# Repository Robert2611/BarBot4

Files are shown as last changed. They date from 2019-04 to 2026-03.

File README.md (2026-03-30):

# BarBot4

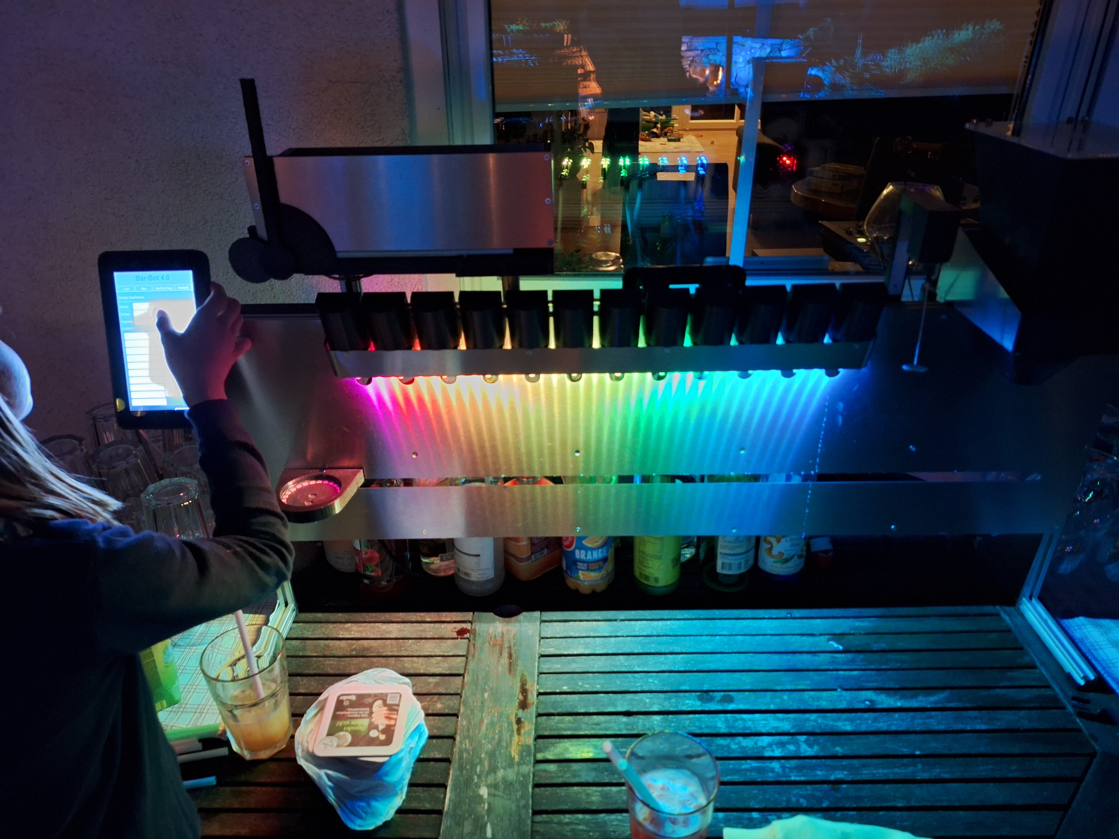
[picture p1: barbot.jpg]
BarBot4


BarBot4 is a high-end, automated cocktail-mixing machine designed for precision and ease of use. It combines a Raspberry Pi-powered touch interface with modular microcontroller-based hardware to deliver perfectly mixed drinks every time.

## ✨ Features

- **Automated Mixing**: Precise control over ingredient dispensing and sequence.
- **Modular Design**: Support for peripheral modules like mixers, crushers, and straw dispensers.
- **Smart Scale Integration**: Real-time weight tracking for accurate pours.
- **Touchscreen GUI**: Modern, user-friendly interface built with PyQt5.
- **Customizable Recipes**: Easily create and manage your own cocktail database.
- **Wireless Communication**: Bluetooth-based control between the Pi and hardware sub-modules.

## 🛠️ Hardware Requirements

To build a BarBot4, you will need:
- **Main Controller**: Raspberry Pi (Bookworm or Trixie recommended) with a touchscreen.
- **Mainboard**: ESP32-based controller for motor and pump management.
- **Balance Board (Mandatory)**: An Atmega328p-based module for accurate weight sensing.
    - **Sensor**: HX711 Load Cell amplifier for weight measurement.
- **Optional Sub-modules**: AVR (Arduino) based modules for specific functions (e.g., Ice Crusher, Mixer, Straw Dispenser).
- **Firmware**: Pre-compiled binaries for all modules are available in the [GitHub Releases](https://github.com/Robert2611/BarBot4/releases).

## 🚀 Quick Start

### 1. Firmware Installation
For ease of setup, pre-compiled firmware binaries are automatically generated and attached to each [GitHub Release](https://github.com/Robert2611/BarBot4/releases).

1. Download the `firmware.zip` from the latest release.
2. Extract the archive on a Windows PC.
3. Run `flash.bat` and follow the on-screen instructions to flash your Mainboard (ESP32) or sub-modules (Atmega328p).
   - *Note: Flashing scripts for Linux/macOS users can be found in the `/firmware` directory.*

### 2. Pi Software Installation
The easiest way to set up the BarBot software on a fresh Raspberry Pi OS is to use the automated install script:

```bash
curl -sSL https://raw.githubusercontent.com/Robert2611/BarBot4/master/raspberry/install.sh | bash
```

This script handles dependencies, virtual environment setup, and system configuration. **It also configures the application to start automatically on boot**, so there is no need to run it manually after the initial setup.

## 🛠️ Development

If you are developing for BarBot4 or need to run it manually for testing, you can use the following commands:

### Running BarBot Manually
- `barbot`: Start the standard interface.
- `barbot-demo`: Start in demo mode (uses mockup hardware for testing).
- `barbot-with-log`: Start with console logging enabled.

### Local Installation
To install the package in editable mode from the repository:
```bash
cd raspberry
pip install -e .
```

## 📂 Project Structure

The project is organized to separate physical design, electronics, and software:
- `/CAD`: 3D models for the chassis and components.
- `/elektronik`: PCB designs and schematics.
- `/firmware`: Microcontroller source code (C++/PlatformIO).
- `/raspberry`: Main Python application logic and GUI.

For a detailed breakdown of all directories, please refer to [README_STRUCTURE.md](./README_STRUCTURE.md).

## 🤝 Contributing

Contributions are welcome! Whether it's a new recipe, a bug fix, or a feature request, feel free to open an issue or submit a pull request.

## 📜 License
[MIT](https://choosealicense.com/licenses/mit/)

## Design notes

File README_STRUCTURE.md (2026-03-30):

# BarBot4 Project Structure

This file provides an overview of the folder organization for the BarBot4 project.

## Root Directory
- `/CAD`: 3D models and mechanical designs for the bar bot's physical structure.
- `/elektronik`: PCB designs, schematics, and other electronic documentation.
- `/firmware`: Source code for all microcontroller-based components.
    - `/mainboard`: Primary controller firmware (PlatformIO project).
    - `/balance`: Firmware for the integrated scale/balance.
    - `/shared`: Common code and headers shared across multiple firmware projects.
    - `/mixer`, `/crusher`, `/straw`, `/sugar`: Firmware for specialized peripheral modules.
- `/raspberry`: Main application and control software running on a Raspberry Pi.
    - `/recipe-collections`: Organized recipe sets (e.g., `standard`, `party-set`).
    - `/barbot`: The core Python source code.
        - `/gui`: PyQt5-based user interface components.
        - `/logic`: Core business logic, hardware interaction, and cocktail preparation flows.
        - `/test`: Unit tests and integration tests for the Python application.
    - `install.sh`: Automated setup script for initializing the Raspberry Pi environment.
- `/info`: General project documentation, build guides, and auxiliary information.

## Technology Stack
- **Firmware**: C++ (ESP32 for the Mainboard, AVR/Arduino for sub-modules) managed via PlatformIO.
- **Pi App**: Python 3 with PyQt5 for the GUI.
- **Hardware Communication**: Serial/Bluetooth-based protocols between the Raspberry Pi and sub-modules.

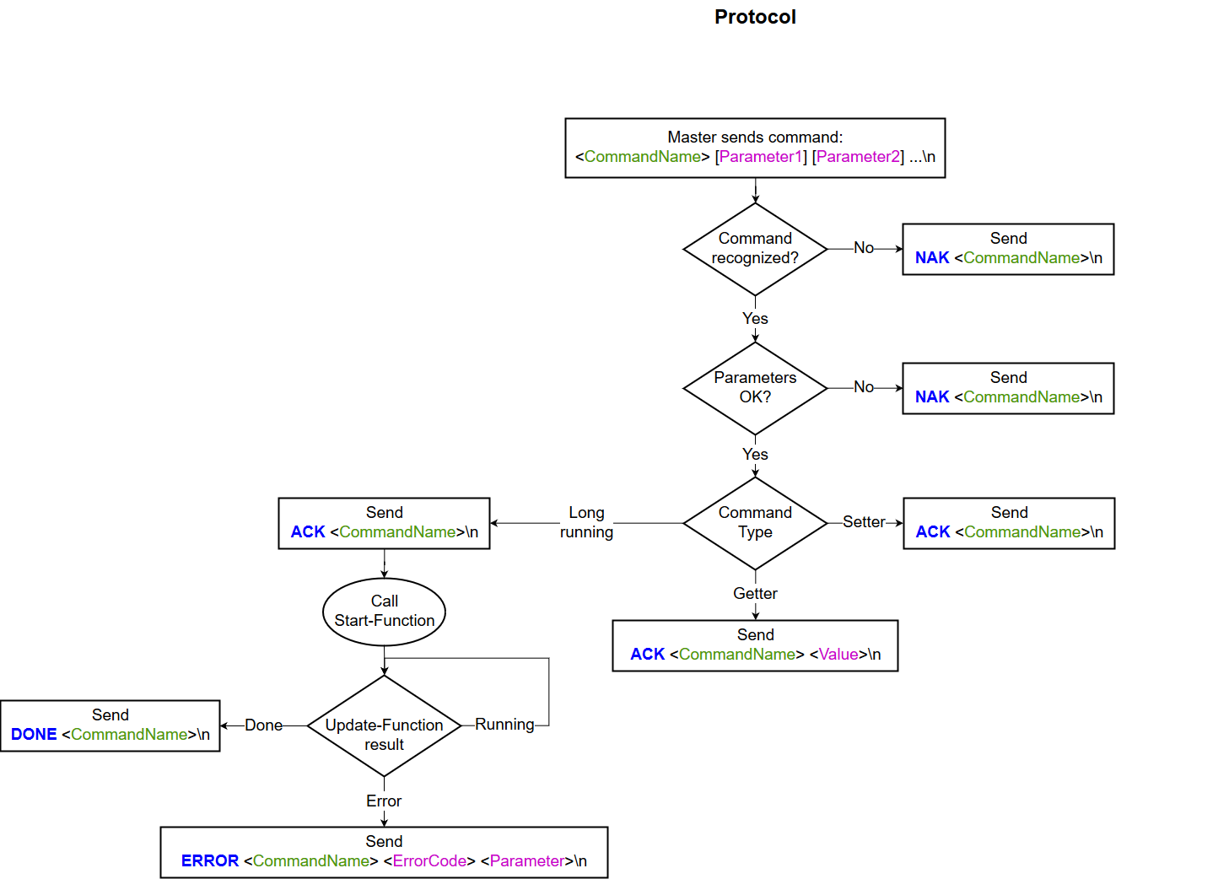
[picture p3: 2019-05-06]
info/Protocol Chart.png

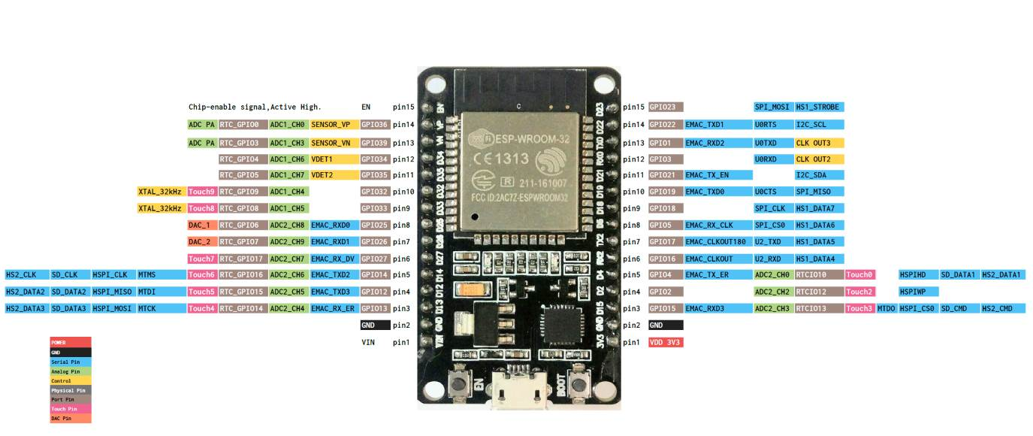
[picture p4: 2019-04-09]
info/ESP32 ports.bmp

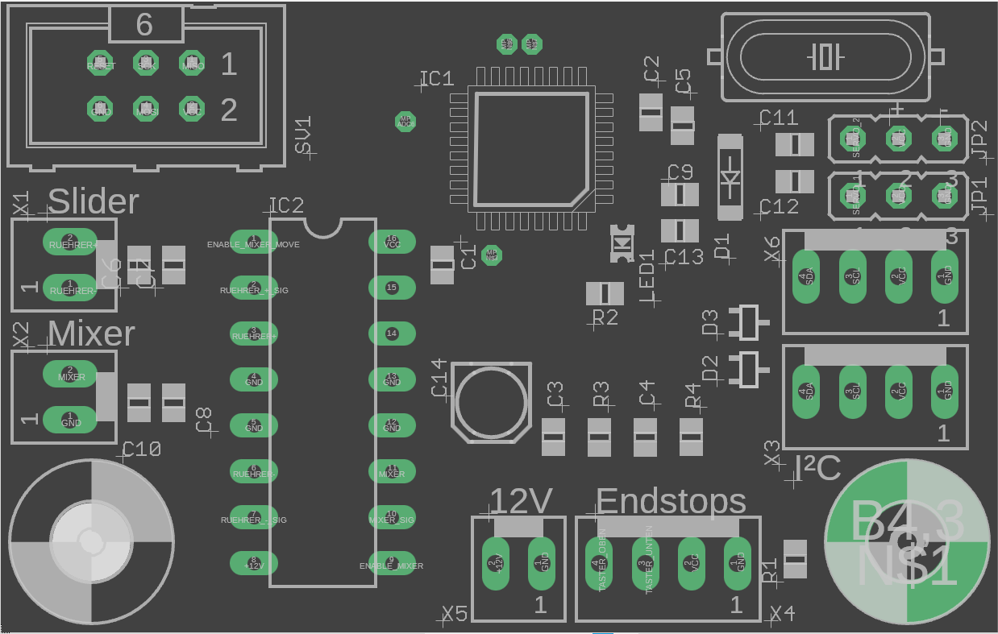
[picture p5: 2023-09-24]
elektronik/Mixer/Mixer Board.png

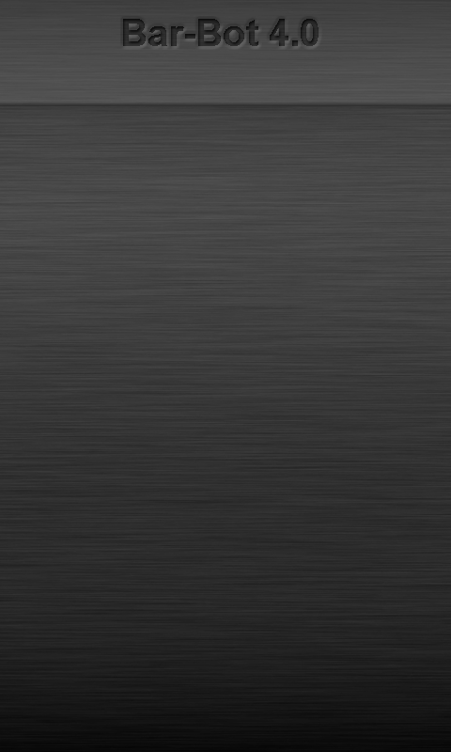
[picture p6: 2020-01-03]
raspberry/barbot/gui/asset/Background.png

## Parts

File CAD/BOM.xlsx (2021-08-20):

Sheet: Kaufteile
Artikelnummer | Beschreibung | Lieferant/Platform | Artikelnummer/-name | Link | Anzahl/Länge pro VE | Preis pro VE | Verpackungs Einheit (VE) | Preis pro Stück/Meter
KT-001 | Pumpe | Ali Express |  | https://www.aliexpress.com/item/32902208606.html | 1 | 4.00 € |  | 4.00 €
KT-002 | DC Motor für Rührer | ebay | Gleichstrommotor Johnson 20703 |  | 3 | 8.67 € |  | 2.89 €
KT-003 | Schlauch | Schlauch-profi.de | Silikonschlauch Lebensmittel 6 x 8 mm |  | 25 | 36.95 € |  | 1.48 €
KT-004 | Neopixel Stripe | Ali Express | WS2812B stripe, 60 LED/Meter | https://www.aliexpress.com/item/32956009458.html | 5 | 16.59 € | m | 3.32 €
KT-005 | Rührer | eBay | Milchaufschäumer | https://www.ebay.de/itm/202533912887 | 1 | 4.89 € |  | 4.89 €
KT-006 | Zahnriemen und Zahnräder | Ali Express | 2x Riemenscheibe (20Zähne) 2,5m Zahnriemen 2x Riemenscheibe mit Kugellager | https://www.aliexpress.com/item/4000091123800.html | 1 | 3.38 € |  | 3.38 €
KT-007 | Rad | Ali Express | V-Slot wheel POM | https://www.aliexpress.com/item/32777946833.html | 10 | 5.97 € |  | 0.60 €
KT-008 | V-Slot Profil | Jamoprint | V Slot Profile 20x40 | https://jamoprint.com/ | 3 | 57.75 € |  | 19.25 €
KT-009 | Schrittmotor | eBay | NEMA 17 | https://www.ebay.de/itm/5PCS-Schrittmotor-Nema-17-Stepper-Motor-42Ncm-1-5-A-4-Draht-Fur-3D-Drucker-DIY/293278143194 | 5 | 35.99 € |  | 7.20 €
KT-010 | Alu Profil |  |  |  | 1 | 3.20 € | m | 3.20 €
KT-011 | Filament | Prusa | PETG Galaxy Black | https://shop.prusa3d.com/de/prusament/1006-prusament-petg-prusa-galaxy-black-1kg.html | 1 | 29.99 € | kg | 29.99 €
KT-012 | LED Ring | Ali Express | 24 LEDs | https://www.aliexpress.com/item/33040868012.html | 1 | 2.52 € |  | 2.52 €
KT-013 | Rollenschalter | eBay | KW12-3 Micro | https://www.ebay.de/itm/192740457273 | 10 | 2.22 € |  | 0.22 €
KT-014 | Alu Winkel | eBay |  |  | 1.5 | 22.96 € | m | 15.31 €
KT-015 | Motor auf u. ab | eBay | 12V 100RPM | https://www.ebay.de/itm/DC-3V-6V-12V-100RPM-Micro-Speed-Reduction-Gear-Motor-Metal-Gearbox-Wheel-Shaft/273996287398 | 5 | 13.30 € |  | 2.66 €
KT-016 | Wiegebalken | Ali Express | 1 kg | https://www.aliexpress.com/item/32864971873.html | 1 | 1.89 € |  | 1.89 €
KT-017 | Igus-Schiene | Igus | NS-01-17, Länge: 160 mm | https://www.igus.de/product/722 | 3 | 17.34 € |  | 5.78 €
KT-018 | Igus-Schlitten | Igus | NW-02-17 | https://www.igus.de/product/920 | 11 | 25.03 € |  | 2.28 €
KT-019 | Servo klein | eBay | Microservo SG90 | https://www.ebay.de/itm/Micro-SG90-Servo-Motor-9G-fur-RC-Hubschrauber-Flugzeug-Arduino-Control-mini/174238436675 | 10 | 15.59 € |  | 1.56 €
KT-020 | Servo groß | eBay |  | https://www.ebay.de/itm/1-4-Digital-Metall-Gear-RC-MG996R-Lenk-Servo-55g-15Kg-Upgrade-RC-Universe/233464162034 | 4 | 16.29 € |  | 4.07 €
KT-021 | Energiekette | Ali Express | Innere Höhe 7mm | https://www.aliexpress.com/item/32214281467.html | 1 | 4.93 € |  | 4.93 €
KT-022 | Raspberry Pi | Raspishop | Raspberry Pi 4 | https://www.rasppishop.de/Raspberry-Pi-4-Modell-B-2GB-SDRAM | 1 | 39.19 € |  | 39.19 €
KT-023 | Touchscreen | Raspishop | Raspberry Pi 7" Touchscreen Display | https://www.rasppishop.de/Raspberry-Pi-7-Touchscreen-Display | 1 | 71.99 € |  | 71.99 €
KT-024 | Netzteil | Raspishop | 5,1V 2,5A Micro-USB Steckernetzteil | https://www.rasppishop.de/51V-25A-Micro-USB-Steckernetzteil | 1 | 7.99 € |  | 7.99 €
KT-025 | Abdeckblech | laserteile4you |  |  | 6 | 100.98 € |  | 16.83 €
KT-026 | Abdeckblech Pumpen | laserteile4you |  |  | 6 | 41.28 € |  | 6.88 €
KT-027 | PMMA | eBay | 3mm x (250mm x 200mm) | https://www.ebay.de/itm/Plexi-Platte-2-15-mm-PMMA-Acrylglas-Acrylplatte-Zuchnit-Schild-250-500-mm/324015302606 | 8 | 5.82 € | Scheiben | 0.73 €
KT-028 | SD-Karte | Raspishop | 16 GB | https://www.rasppishop.de/Sandisk-microSDHC-UHS-I-A1-16GB-Class10 | 1 | 7.30 € |  | 7.30 €
KT-029 | Motor Crusher |  |  |  | 1 | 25.00 € |  | 25.00 €
KT-030 | Eiscrusher | gastro-spirit.de |  | https://www.gastro-spirit.de/eiszerkleinerer-mit-handkurbel-ohne-saugfuss-1399001.html | 6 | 50.64 € |  | 8.44 €
KT-050 | DIN 912 M3x30 | Frantos |  |  | 100 | 7.00 € |  | 0.07 €
KT-051 | Mutter M3 | Frantos |  |  | 1000 | 9.28 € |  | 0.01 €
KT-052 | DIN 912 M4x14 | Frantos |  |  | 500 | 20.83 € |  | 0.04 €
KT-053 | Unterlegscheibe A4,3 | Frantos | DIN 125 A M4 |  | 1000 | 5.47 € |  | 0.01 €
KT-054 | Nutenstein M4 | Ali Express | 20-M4 | https://www.aliexpress.com/item/33053406103.html | 20 | 3.00 € |  | 0.15 €
KT-055 | Hammerkopf Mutter M4 | Ali Express |  | https://www.aliexpress.com/item/32333227356.html | 100 | 7.00 € |  | 0.07 €
KT-056 | DIN 912 M3x6 | Frantos |  |  | 100 | 4.00 € |  | 0.04 €
KT-057 | DIN 912 M5x25 | Frantos |  |  | 500 | 34.87 € |  | 0.07 €
KT-058 | Mutter M5 | Frantos |  |  | 1000 | 15.35 € |  | 0.02 €
KT-059 | Unterlegscheibe A5,3 | Frantos | DIN 125 A M5 |  | 1000 | 7.02 € |  | 0.01 €
KT-060 | Karosseriescheibe M5 | Frantos | 5,3x15 |  | 500 | 10.41 € |  | 0.02 €
KT-061 | DIN 7991 M5x30 | Frantos |  |  | 200 | 11.71 € |  | 0.06 €
KT-062 | DIN 912 M3x10 | Frantos |  |  | 100 | 2.15 € |  | 0.02 €
KT-063 | Unterlegscheibe A3,2 | Frantos | DIN 125 A M3 |  | 1000 | 4.52 € |  | 0.00452 €
KT-064 | DIN 7991 M3x8 | Frantos |  |  | 100 | 3.07 € |  | 0.03 €
KT-065 | DIN 7991 M4x18 | Frantos |  |  | 500 | 14.40 € |  | 0.03 €
KT-066 | DIN 7991 M4x12 | Frantos |  |  | 500 | 10.89 € |  | 0.02 €
KT-067 | Nutenstein M3 | Ali Express | 20-M3 | https://www.aliexpress.com/item/33053406103.html | 20 | 3.00 € |  | 0.15 €
KT-068 | Flanschkopfschraube M5x16 | Frantos | ISO 7380-2 |  | 500 | 25.05 € |  | 0.05 €
KT-069 | DIN 912 M4x10 | Frantos |  |  | 500 | 17.55 € |  | 0.04 €
KT-070 | DIN 7991 M3x10 | Frantos |  |  | 100 | 3.14 € |  | 0.03 €
KT-071 | DIN 912 M5x10 | Frantos |  |  | 500 | 22.49 € |  | 0.04 €
KT-072 | Nutenstein M5 | Ali Express | 20-M5 | https://www.aliexpress.com/item/33053406103.html | 20 | 3.00 € |  | 0.15 €
KT-073 | DIN 912 M2x20 | Frantos |  |  | 500 | 24.81 € |  | 0.05 €
KT-074 | Mutter M2 | Frantos |  |  | 500 | 5.36 € |  | 0.01 €
KT-075 | DIN 7991 M3x12 | Frantos |  |  | 100 | 3.01 € |  | 0.03 €
KT-076 | DIN 912 M3x20 | Frantos |  |  | 100 | 2.88 € |  | 0.03 €
KT-077 | Hammerkopf Mutter M3 | Ali Express |  | https://www.aliexpress.com/item/32333227356.html | 100 | 7.00 € |  | 0.07 €
KT-078 | Gewindestift M3x5 | Frantos |  |  | 500 | 7.08 € |  | 0.01 €
KT-079 | O-Ring 45x2,5 | Fortuna
KT-080 | Abdeckblech Strohhalmmagazin vorne | laserteile4you |  |  | 1 | 6.85 € |  | 6.85 €
KT-081 | Abdeckblech Strohhalmmagazin hinten | laserteile4you |  |  | 1 | 6.74 € |  | 6.74 €
KT-082 | DIN 933 M6x20
KT-083 | Knotenblech |  |  |  | 2 |  |  | 0.00 €
KT-084 | DIN 7991 M3x16 | Frantos |  |  | 100 | 3.00 € |  | 0.03 €
KT-085 | Vierkantmutter M3 |  |  |  | 1 | 0.00 € |  | 0.00 €
KT-086 | Vierkant 8x8
KT-087 | Stecknuss SW13
KT-088 | Crusher Blech1
KT-089 | Crusher Blech2
KT-090 | Batterie Crusher
KT-999 | Dummy |  |  |  | 1 | 0.00 € |  | 0.00 €

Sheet: Fertigungsteile
Artikelnummer | Beschreibung | Artikelnummer Kaufteil | Beschreibung Kaufteil | Menge Kaufteil | Preis
FT-001 | Profil 20x20 400 mm | KT-010 | Alu Profil | 0.4 | 1.28 €
FT-002 | Profil 20x20 300 mm | KT-010 | Alu Profil | 0.3 | 0.96 €
FT-003 | Profil 20x20 1040 mm | KT-010 | Alu Profil | 1.04 | 3.33 €
FT-004 | Profil 20x20 1000 mm | KT-010 | Alu Profil | 1 | 3.20 €
FT-005 | V-Slot Profil 1000 mm | KT-008 | V-Slot Profil | 1 | 19.25 €
FT-006 | Schlitten | KT-014 | Alu Winkel | 0.1 | 1.53 €
FT-007 | PMMA Scheibe | KT-027 | PMMA | 1 | 0.73 €
FT-008 | Igus Schiene mit Fase | KT-017 | Igus-Schiene | 1 | 5.78 €
FT-009 | Rührer Unterstüztungswinkel | KT-014 | Alu Winkel | 0.016 | 0.24 €
FT-010 | Profil 20x20 90mm | KT-010 | Alu Profil | 0.09 | 0.29 €
FT-011 | Wiegebalken | KT-016 | Wiegebalken |  | 0.00 €
FT-012 | Profil 20x20 100 mm | KT-010 | Alu Profil |  | 0.00 €
FT-013 | Welle | KT-086 | Vierkant 8x8 |  | #VALUE!
DT-001 | Schrittmotorhalter | KT-011 | Filament | 0.016 | 0.48 €
DT-002 | Riemenumlenkung | KT-011 | Filament | 0.021 | 0.63 €
DT-003 | Box Hauptplatine | KT-011 | Filament | 0.064 | 1.92 €
DT-004 | Deckel Hauptplatine | KT-011 | Filament | 0.019 | 0.57 €
DT-005 | Klemme Pumpenhalterung | KT-011 | Filament | 0.02 | 0.60 €
DT-006 | Pumpenhalterung | KT-011 | Filament | 0.013 | 0.39 €
DT-007 | Teller Teil 1 | KT-011 | Filament | 0.015 | 0.45 €
DT-008 | Teller Teil 2 | KT-011 | Filament | 0.027 | 0.81 €
DT-009 | Teller Teil 3 | KT-011 | Filament | 0.004 | 0.12 €
DT-010 | Riemenbefestigung rechts | KT-011 | Filament | 0.008 | 0.24 €
DT-011 | Riemenbefestigung links | KT-011 | Filament | 0.008 | 0.24 €
DT-012 | Abdeckplatte Rührermotor | KT-011 | Filament | 0.006 | 0.18 €
DT-013 | Box Wiegeplatine | KT-011 | Filament | 0.032 | 0.96 €
DT-014 | Deckel Wiegeplatine | KT-011 | Filament | 0.007 | 0.21 €
DT-015 | Schlauchführung | KT-011 | Filament | 0.005 | 0.15 €
DT-016 | Box Rührerplatine | KT-011 | Filament | 0.034 | 1.02 €
DT-017 | Deckel Rührerplatine | KT-011 | Filament | 0.007 | 0.21 €
DT-018 | Grundplatte Rührer | KT-011 | Filament | 0.042 | 1.26 €
DT-019 | Motorklemme | KT-011 | Filament | 0.003 | 0.09 €
DT-020 | Zahnrad | KT-011 | Filament | 0.003 | 0.09 €
DT-022 | Zahnstange Rührer | KT-011 | Filament | 0.039 | 1.17 €
DT-023 | Halterung Rührermotor | KT-011 | Filament | 0.038 | 1.14 €
DT-024 | Strohhalmmagazin | KT-011 | Filament | 0.163 | 4.89 €
DT-025 | Reibrad | KT-011 | Filament | 0.006 | 0.18 €
DT-026 | Motorhalterung Reibrad | KT-011 | Filament |  | 0.00 €
DT-027 | Verbindung Servo zu Schraube | KT-011 | Filament |  | 0.00 €
DT-028 | Drehbarer Arm | KT-011 | Filament |  | 0.00 €
DT-029 | Displayhalter | KT-011 | Filament |  | 0.00 €
DT-030 | Display Standfuß | KT-011 | Filament |  | 0.00 €
DT-031 | Kettenverbindung | KT-011 | Filament |  | 0.00 €
DT-032 | Verbinder Griff | KT-011 | Filament |  | 0.00 €
DT-033 | Griff | KT-011 | Filament |  | 0.00 €
DT-034 | Profilclip | KT-011 | Filament |  | 0.00 €
DT-035 | Adapter Displayhalterung | KT-011 | Filament |  | 0.00 €
DT-036 | Trichter Crusher | KT-011 | Filament |  | 0.00 €
DT-037 | Motorplatte Scheibenwischermotor | KT-011 | Filament |  | 0.00 €
DT-038 | Blende Crusher | KT-011 | Filament |  | 0.00 €
DT-039 | Eiswürfelbehälter | KT-011 | Filament |  | 0.00 €
DT-040 | Lagerung Crusherwelle | KT-011 | Filament |  | 0.00 €
DT-041 | Buchse/Fixierung | KT-011 | Filament |  | 0.00 €
DT-042 | Buchse | KT-011 | Filament |  | 0.00 €
DT-043 | Crusher Deckel | KT-011 | Filament |  | 0.00 €
DT-044 | Scharnier Teil1 | KT-011 | Filament |  | 0.00 €
DT-045 | Scharnier Teil2 | KT-011 | Filament |  | 0.00 €

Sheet: BOM
Rubrik | Artikelnummer | Anzahl | Beschreibung | Gesamtpreis | Ist Fertigungsteil | Artikelnummer Kaufteil | Menge Kaufteil | Beschreibung Kaufteil | Info
Rahmen | FT-001 | 2 | Profil 20x20 400 mm | 2.56 € | TRUE | KT-010 | 0.8 | Alu Profil
Rahmen | FT-002 | 2 | Profil 20x20 300 mm | 1.92 € | TRUE | KT-010 | 0.6 | Alu Profil
Rahmen | FT-003 | 1 | Profil 20x20 1040 mm | 3.33 € | TRUE | KT-010 | 1.04 | Alu Profil
Rahmen | FT-004 | 1 | Profil 20x20 1000 mm | 3.20 € | TRUE | KT-010 | 1 | Alu Profil
Rahmen | FT-005 | 1 | V-Slot Profil 1000 mm | 19.25 € | TRUE | KT-008 | 1 | V-Slot Profil
Rahmen | KT-004 | 1 | Neopixel Stripe | 3.32 € | FALSE | KT-004 | 1 | Neopixel Stripe
Rahmen | KT-025 | 1 | Abdeckblech | 16.83 € | FALSE | KT-025 | 1 | Abdeckblech
Rahmen | KT-009 | 1 | Schrittmotor | 7.20 € | FALSE | KT-009 | 1 | Schrittmotor
Rahmen | KT-013 | 1 | Rollenschalter | 0.22 € | FALSE | KT-013 | 1 | Rollenschalter
Rahmen | DT-001 | 1 | Schrittmotorhalter | 0.48 € | TRUE | KT-011 | 0.016 | Filament
Rahmen | DT-002 | 1 | Riemenumlenkung | 0.63 € | TRUE | KT-011 | 0.021 | Filament
Rahmen | DT-003 | 1 | Box Hauptplatine | 1.92 € | TRUE | KT-011 | 0.064 | Filament
Rahmen | DT-004 | 1 | Deckel Hauptplatine | 0.57 € | TRUE | KT-011 | 0.019 | Filament
Rahmen | KT-068 | 6 | Flanschkopfschraube M5x16 | 0.30 € | FALSE | KT-068 | 6 | Flanschkopfschraube M5x16
Rahmen | KT-069 | 3 | DIN 912 M4x10 | 0.11 € | FALSE | KT-069 | 3 | DIN 912 M4x10 | Box Hauptplatine
Rahmen | KT-053 | 3 | Unterlegscheibe A4,3 | 0.02 € | FALSE | KT-053 | 3 | Unterlegscheibe A4,3 | Box Hauptplatine
Rahmen | KT-054 | 3 | Nutenstein M4 | 0.45 € | FALSE | KT-054 | 3 | Nutenstein M4 | Box Hauptplatine
Rahmen | KT-056 | 4 | DIN 912 M3x6 | 0.16 € | FALSE | KT-056 | 4 | DIN 912 M3x6 | Box Hauptplatine
Rahmen | KT-071 | 8 | DIN 912 M5x10 | 0.36 € | FALSE | KT-071 | 8 | DIN 912 M5x10 | Motorhalter + Umlenker
Rahmen | KT-059 | 9 | Unterlegscheibe A5,3 | 0.06 € | FALSE | KT-059 | 9 | Unterlegscheibe A5,3 | Motorhalter + Umlenker
Rahmen | KT-057 | 1 | DIN 912 M5x25 | 0.07 € | FALSE | KT-057 | 1 | DIN 912 M5x25 | Motorhalter + Umlenker
Rahmen | KT-072 | 8 | Nutenstein M5 | 1.20 € | FALSE | KT-072 | 8 | Nutenstein M5 | Motorhalter + Umlenker
Rahmen | KT-064 | 4 | DIN 7991 M3x8 | 0.12 € | FALSE | KT-064 | 4 | DIN 7991 M3x8 | Motorhalter + Umlenker
Rahmen | KT-073 | 2 | DIN 912 M2x20 | 0.10 € | FALSE | KT-073 | 2 | DIN 912 M2x20 | Motorhalter + Umlenker
Rahmen | KT-074 | 2 | Mutter M2 | 0.02 € | FALSE | KT-074 | 2 | Mutter M2 | Motorhalter + Umlenker
Schlitten | FT-006 | 1 | Schlitten | 1.53 € | TRUE | KT-014 | 0.1 | Alu Winkel
Schlitten | KT-007 | 3 | Rad | 1.79 € | FALSE | KT-007 | 3 | Rad
Schlitten | KT-021 | 1 | Energiekette | 4.93 € | FALSE | KT-021 | 1 | Energiekette
Schlitten | KT-006 | 1 | Zahnriemen und Zahnräder | 3.38 € | FALSE | KT-006 | 1 | Zahnriemen und Zahnräder
Schlitten | KT-012 | 1 | LED Ring | 2.52 € | FALSE | KT-012 | 1 | LED Ring
Schlitten | KT-016 | 1 | Wiegebalken | 1.89 € | FALSE | KT-016 | 1 | Wiegebalken
Schlitten | FT-007 | 1 | PMMA Scheibe | 0.73 € | TRUE | KT-027 | 1 | PMMA
Schlitten | DT-007 | 1 | Teller Teil 1 | 0.45 € | TRUE | KT-011 | 0.015 | Filament
Schlitten | DT-008 | 1 | Teller Teil 2 | 0.81 € | TRUE | KT-011 | 0.027 | Filament
Schlitten | DT-009 | 1 | Teller Teil 3 | 0.12 € | TRUE | KT-011 | 0.004 | Filament
Schlitten | DT-010 | 1 | Riemenbefestigung rechts | 0.24 € | TRUE | KT-011 | 0.008 | Filament
Schlitten | DT-011 | 1 | Riemenbefestigung links | 0.24 € | TRUE | KT-011 | 0.008 | Filament
Schlitten | DT-012 | 1 | Abdeckplatte Rührermotor | 0.18 € | TRUE | KT-011 | 0.006 | Filament
Schlitten | DT-013 | 1 | Box Wiegeplatine | 0.96 € | TRUE | KT-011 | 0.032 | Filament
Schlitten | DT-014 | 1 | Deckel Wiegeplatine | 0.21 € | TRUE | KT-011 | 0.007 | Filament
Schlitten | KT-057 | 2 | DIN 912 M5x25 | 0.14 € | FALSE | KT-057 | 2 | DIN 912 M5x25
Schlitten | KT-058 | 6 | Mutter M5 | 0.09 € | FALSE | KT-058 | 6 | Mutter M5
Schlitten | KT-059 | 5 | Unterlegscheibe A5,3 | 0.04 € | FALSE | KT-059 | 5 | Unterlegscheibe A5,3
Schlitten | KT-060 | 1 | Karosseriescheibe M5 | 0.02 € | FALSE | KT-060 | 1 | Karosseriescheibe M5
Schlitten | KT-061 | 1 | DIN 7991 M5x30 | 0.06 € | FALSE | KT-061 | 1 | DIN 7991 M5x30
Schlitten | KT-062 | 5 | DIN 912 M3x10 | 0.11 € | FALSE | KT-062 | 5 | DIN 912 M3x10
Schlitten | KT-063 | 4 | Unterlegscheibe A3,2 | 0.02 € | FALSE | KT-063 | 4 | Unterlegscheibe A3,2
Schlitten | KT-051 | 5 | Mutter M3 | 0.05 € | FALSE | KT-051 | 5 | Mutter M3
Schlitten | KT-070 | 2 | DIN 7991 M3x10 | 0.06 € | FALSE | KT-070 | 2 | DIN 7991 M3x10
Schlitten | KT-064 | 4 | DIN 7991 M3x8 | 0.12 € | FALSE | KT-064 | 4 | DIN 7991 M3x8
Schlitten | KT-056 | 2 | DIN 912 M3x6 | 0.08 € | FALSE | KT-056 | 2 | DIN 912 M3x6
Schlitten | KT-065 | 3 | DIN 7991 M4x18 | 0.09 € | FALSE | KT-065 | 3 | DIN 7991 M4x18
Schlitten | KT-066 | 1 | DIN 7991 M4x12 | 0.02 € | FALSE | KT-066 | 1 | DIN 7991 M4x12
Schlitten | KT-067 | 2 | Nutenstein M3 | 0.30 € | FALSE | KT-067 | 2 | Nutenstein M3
Display | DT-029 | 1 | Displayhalter | 0.00 € | TRUE | KT-011 | 0 | Filament
Display | DT-030 | 1 | Display Standfuß | 0.00 € | TRUE | KT-011 | 0 | Filament
Display | KT-022 | 1 | Raspberry Pi | 39.19 € | FALSE | KT-022 | 1 | Raspberry Pi
Display | KT-023 | 1 | Touchscreen | 71.99 € | FALSE | KT-023 | 1 | Touchscreen
Display | KT-024 | 1 | Netzteil | 7.99 € | FALSE | KT-024 | 1 | Netzteil
Display | KT-028 | 1 | SD-Karte | 7.30 € | FALSE | KT-028 | 1 | SD-Karte
Pumpe | KT-001 | 12 | Pumpe | 48.00 € | FALSE | KT-001 | 12 | Pumpe
Pumpe | KT-003 | 3.6 | Schlauch | 5.32 € | FALSE | KT-003 | 3.6 | Schlauch
Pumpe | DT-005 | 12 | Klemme Pumpenhalterung | 7.20 € | TRUE | KT-011 | 0.24 | Filament
Pumpe | DT-006 | 12 | Pumpenhalterung | 4.68 € | TRUE | KT-011 | 0.156 | Filament
Pumpe | KT-050 | 24 | DIN 912 M3x30 | 1.68 € | FALSE | KT-050 | 24 | DIN 912 M3x30
Pumpe | KT-051 | 36 | Mutter M3 | 0.33 € | FALSE | KT-051 | 36 | Mutter M3
Pumpe | KT-052 | 24 | DIN 912 M4x14 | 1.00 € | FALSE | KT-052 | 24 | DIN 912 M4x14
Pumpe | KT-053 | 24 | Unterlegscheibe A4,3 | 0.13 € | FALSE | KT-053 | 24 | Unterlegscheibe A4,3
Pumpe | KT-055 | 24 | Hammerkopf Mutter M4 | 1.68 € | FALSE | KT-055 | 24 | Hammerkopf Mutter M4
Pumpe | KT-056 | 12 | DIN 912 M3x6 | 0.48 € | FALSE | KT-056 | 12 | DIN 912 M3x6
Rührer | KT-002 | 1 | DC Motor für Rührer | 2.89 € | FALSE | KT-002 | 1 | DC Motor für Rührer
Rührer | KT-005 | 1 | Rührer | 4.89 € | FALSE | KT-005 | 1 | Rührer
Rührer | KT-017 | 1 | Igus-Schiene | 5.78 € | FALSE | KT-017 | 1 | Igus-Schiene
Rührer | KT-018 | 2 | Igus-Schlitten | 4.55 € | FALSE | KT-018 | 2 | Igus-Schlitten
Rührer | KT-015 | 1 | Motor auf u. ab | 2.66 € | FALSE | KT-015 | 1 | Motor auf u. ab
Rührer | FT-009 | 1 | Rührer Unterstüztungswinkel | 0.24 € | TRUE | KT-014 | 0.016 | Alu Winkel
Rührer | FT-010 | 1 | Profil 20x20 90mm | 0.29 € | TRUE | KT-010 | 0.09 | Alu Profil
Rührer | KT-013 | 2 | Rollenschalter | 0.44 € | FALSE | KT-013 | 2 | Rollenschalter
Rührer | DT-012 | 1 | Abdeckplatte Rührermotor | 0.18 € | TRUE | KT-011 | 0.006 | Filament
Rührer | DT-016 | 1 | Box Rührerplatine | 1.02 € | TRUE | KT-011 | 0.034 | Filament
Rührer | DT-017 | 1 | Deckel Rührerplatine | 0.21 € | TRUE | KT-011 | 0.007 | Filament
Rührer | DT-018 | 1 | Grundplatte Rührer | 1.26 € | TRUE | KT-011 | 0.042 | Filament
Rührer | DT-019 | 1 | Motorklemme | 0.09 € | TRUE | KT-011 | 0.003 | Filament
Rührer | DT-020 | 1 | Zahnrad | 0.09 € | TRUE | KT-011 | 0.003 | Filament
Rührer | DT-022 | 1 | Zahnstange Rührer | 1.17 € | TRUE | KT-011 | 0.039 | Filament
Rührer | DT-023 | 1 | Halterung Rührermotor | 1.14 € | TRUE | KT-011 | 0.038 | Filament
Rührer | KT-075 | 4 | DIN 7991 M3x12 | 0.12 € | FALSE | KT-075 | 4 | DIN 7991 M3x12 | Zahnstange an Schlitten
Rührer | KT-069 | 2 | DIN 912 M4x10 | 0.07 € | FALSE | KT-069 | 2 | DIN 912 M4x10 | Grundplatte an Profil
Rührer | KT-053 | 2 | Unterlegscheibe A4,3 | 0.01 € | FALSE | KT-053 | 2 | Unterlegscheibe A4,3 | Grundplatte an Profil
Rührer | KT-055 | 2 | Hammerkopf Mutter M4 | 0.14 € | FALSE | KT-055 | 2 | Hammerkopf Mutter M4 | Grundplatte an Profil
Rührer | KT-068 | 1 | Flanschkopfschraube M5x16 | 0.05 € | FALSE | KT-068 | 1 | Flanschkopfschraube M5x16 | Profil an Profil
Rührer | KT-077 | 2 | Hammerkopf Mutter M3 | 0.14 € | FALSE | KT-077 | 2 | Hammerkopf Mutter M3 | Schiene an Profil
Rührer | KT-075 | 2 | DIN 7991 M3x12 | 0.06 € | FALSE | KT-075 | 2 | DIN 7991 M3x12 | Schiene an Profil
Rührer | KT-062 | 2 | DIN 912 M3x10 | 0.04 € | FALSE | KT-062 | 2 | DIN 912 M3x10 | DT an Winkel
Rührer | KT-084 | 2 | DIN 7991 M3x16 | 0.06 € | FALSE | KT-084 | 2 | DIN 7991 M3x16 | DT an Winkel
Rührer | KT-075 | 1 | DIN 7991 M3x12 | 0.03 € | FALSE | KT-075 | 1 | DIN 7991 M3x12 | Abdeckung
Rührer | KT-073 | 4 | DIN 912 M2x20 | 0.20 € | FALSE | KT-073 | 4 | DIN 912 M2x20 | Endschalter
Rührer | KT-074 | 4 | Mutter M2 | 0.04 € | FALSE | KT-074 | 4 | Mutter M2 | Endschalter
Rührer | KT-076 | 2 | DIN 912 M3x20 | 0.06 € | FALSE | KT-076 | 2 | DIN 912 M3x20 | Motorklemme
Rührer | KT-051 | 2 | Mutter M3 | 0.02 € | FALSE | KT-051 | 2 | Mutter M3 | Motorklemme
Rührer | KT-062 | 2 | DIN 912 M3x10 | 0.04 € | FALSE | KT-062 | 2 | DIN 912 M3x10 | Platinenbox
Rührer | KT-063 | 4 | Unterlegscheibe A3,2 | 0.02 € | FALSE | KT-063 | 4 | Unterlegscheibe A3,2 | Platinenbox
Rührer | KT-056 | 2 | DIN 912 M3x6 | 0.08 € | FALSE | KT-056 | 2 | DIN 912 M3x6 | Platinenbox
Rührer | KT-085 | 1 | Vierkantmutter M3 | 0.00 € | FALSE | KT-085 | 1 | Vierkantmutter M3 | Zahnrad
Rührer | KT-078 | 1 | Gewindestift M3x5 | 0.01 € | FALSE | KT-078 | 1 | Gewindestift M3x5 | Zahnrad
Strohhalm | KT-019 | 1 | Servo klein | 1.56 € | FALSE | KT-019 | 1 | Servo klein
Strohhalm | KT-020 | 1 | Servo groß | 4.07 € | FALSE | KT-020 | 1 | Servo groß
Strohhalm | DT-024 | 1 | Strohhalmmagazin | 4.89 € | TRUE | KT-011 | 0.163 | Filament
Strohhalm | DT-025 | 1 | Reibrad | 0.18 € | TRUE | KT-011 | 0.006 | Filament
Strohhalm | DT-026 | 1 | Motorhalterung Reibrad | 0.00 € | TRUE | KT-011 | 0 | Filament
Strohhalm | DT-027 | 1 | Verbindung Servo zu Schraube | 0.00 € | TRUE | KT-011 | 0 | Filament
Strohhalm | DT-028 | 1 | Drehbarer Arm | 0.00 € | TRUE | KT-011 | 0 | Filament
Crusher | KT-029 | 1 | Motor Crusher | 25.00 € | FALSE | KT-029 | 1 | Motor Crusher
Crusher | KT-030 | 1 | Eiscrusher | 8.44 € | FALSE | KT-030 | 1 | Eiscrusher

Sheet: Auswertung
Zeilenbeschriftungen | Summe von Gesamtpreis | Zeilenbeschriftungen | Summe von Gesamtpreis | Summe von Menge Kaufteil | Zeilenbeschriftungen | Gesamtmenge
(Leer) | 36.01 € | Abdeckblech | 20.5 | 1 | KT-001 | 12
Ali Express | 69.97 € | Alu Profil | 11.008 | 3.44 | KT-002 | 1
ebay | 25.75 € | Alu Winkel | 1.530666667 | 0.1 | KT-003 | 3.6
Frantos | 6.50 € | DC Motor für Rührer | 2.89 | 1 | KT-004 | 1
gastro-spirit.de | 8.44 € | DIN 7991 M3x10 | 0.0628 | 2 | KT-005 | 1
Igus | 10.33 € | DIN 7991 M3x12 | 0.0602 | 2 | KT-006 | 1
Jamoprint | 19.25 € | DIN 7991 M3x8 | 0.2456 | 8 | KT-007 | 3
laserteile4you | 20.50 € | DIN 7991 M4x12 | 0.02178 | 1 | KT-008 | 1
Prusa | 20.45 € | DIN 7991 M4x18 | 0.0864 | 3 | KT-009 | 1
Raspishop | 126.47 € | DIN 7991 M5x30 | 0.05855 | 1 | KT-010 | 3.44
Schlauch-profi.de | 5.32 € | DIN 912 M2x20 | 0.29772 | 6 | KT-011 | 0.682
Gesamtergebnis | 348.99 € | DIN 912 M3x10 | 0.1505 | 7 | KT-012 | 1
 |  | DIN 912 M3x20 | 0.0576 | 2 | KT-013 | 1
 |  | DIN 912 M3x30 | 1.68 | 24 | KT-014 | 0.1
 |  | DIN 912 M3x6 | 0.8 | 20 | KT-015 | 1
 |  | DIN 912 M4x10 | 0.1755 | 5 | KT-016 | 1
 |  | DIN 912 M4x14 | 0.99984 | 24 | KT-017 | 1
 |  | DIN 912 M5x10 | 0.35984 | 8 | KT-018 | 2
 |  | DIN 912 M5x25 | 0.20922 | 3 | KT-019 | 1
 |  | Dummy | 0 | 0 | KT-020 | 1
 |  | Eiscrusher | 8.44 | 1 | KT-021 | 1
 |  | Energiekette | 4.93 | 1 | KT-022 | 1
 |  | Filament | 20.45318 | 0.682 | KT-023 | 1
 |  | Flanschkopfschraube M5x16 | 0.3507 | 7 | KT-024 | 1
 |  | Gewindestift M3x5 | 0.01416 | 1 | KT-025 | 1
 |  | Hammerkopf Mutter M3 | 0.07 | 1 | KT-027 | 1
 |  | Hammerkopf Mutter M4 | 1.82 | 26 | KT-028 | 1
 |  | Igus-Schiene | 5.781233333 | 1 | KT-029 | 1
 |  | Igus-Schlitten | 4.551109091 | 2 | KT-030 | 1
 |  | Karosseriescheibe M5 | 0.02082 | 1 | KT-050 | 24
 |  | LED Ring | 2.52 | 1 | KT-051 | 43
 |  | Motor auf u. ab | 2.66 | 1 | KT-052 | 24
 |  | Motor Crusher | 25 | 1 | KT-053 | 29
 |  | Mutter M2 | 0.06432 | 6 | KT-054 | 3
 |  | Mutter M3 | 0.39904 | 43 | KT-055 | 26
 |  | Mutter M5 | 0.0921 | 6 | KT-056 | 20
 |  | Neopixel Stripe | 3.318 | 1 | KT-057 | 3
 |  | Netzteil | 7.99 | 1 | KT-058 | 6
 |  | Nutenstein M3 | 0.6 | 4 | KT-059 | 14
 |  | Nutenstein M4 | 0.45 | 3 | KT-060 | 1
 |  | Nutenstein M5 | 1.2 | 8 | KT-061 | 1
 |  | PMMA | 0.7275 | 1 | KT-062 | 7
 |  | Pumpe | 48 | 12 | KT-063 | 8
 |  | Rad | 1.791 | 3 | KT-064 | 8
 |  | Raspberry Pi | 39.19 | 1 | KT-065 | 3
 |  | Rollenschalter | 0.222 | 1 | KT-066 | 1
 |  | Rührer | 4.89 | 1 | KT-067 | 4
 |  | Schlauch | 5.3208 | 3.6 | KT-068 | 7
 |  | Schrittmotor | 7.198 | 1 | KT-069 | 5
 |  | SD-Karte | 7.3 | 1 | KT-070 | 2
 |  | Servo groß | 4.0725 | 1 | KT-071 | 8
 |  | Servo klein | 1.559 | 1 | KT-072 | 8
 |  | Touchscreen | 71.99 | 1 | KT-073 | 6
 |  | Unterlegscheibe A3,2 | 0.03616 | 8 | KT-074 | 6
 |  | Unterlegscheibe A4,3 | 0.15863 | 29 | KT-075 | 2
 |  | Unterlegscheibe A5,3 | 0.09828 | 14 | KT-076 | 2
 |  | V-Slot Profil | 19.25 | 1 | KT-077 | 1
 |  | Wiegebalken | 1.89 | 1 | KT-078 | 1
 |  | Zahnriemen und Zahnräder | 3.38 | 1 | KT-999 | 0
 |  | Gesamtergebnis | 348.9927491 | 319.822 | Gesamtergebnis | 319.822

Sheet: Bestellungen
Artikelnummer Kaufteil | Beschreibung Kaufteil | Benötigt pro BarBot | Benötigt gesamt | Vorhanden | Bestellt | Noch bestellen | Wer Bestellt?
KT-001 | Pumpe | 12 | 72 | 24 | 13 | 35 | Jeder einzeln
KT-002 | DC Motor für Rührer | 1 | 6 | 1 |  | 5 | -
KT-003 | Schlauch | 3.6 | 21.6 | 30 |  | 0
KT-004 | Neopixel Stripe | 1 | 6 | 5 |  | 1 | Marinus
KT-005 | Rührer | 1 | 6 | 6 |  | 0
KT-006 | Zahnriemen und Zahnräder | 1 | 6 | 2 | 4 | 0
KT-007 | Rad | 3 | 18 | 5 | 10 | 0 | Nils
KT-008 | V-Slot Profil | 1 | 6 | 4 |  | 0 | Nils
KT-009 | Schrittmotor | 1 | 6 | 6 |  | 0
KT-010 | Alu Profil | 3.44 | 20.64 | 25 |  | 0
KT-011 | Filament | 0.682 | 4.092 | 2 |  | 2.092
KT-012 | LED Ring | 1 | 6 | 1 | 5 | 0
KT-013 | Rollenschalter | 1 | 6 | 10 |  | 0
KT-014 | Alu Winkel | 0.1 | 0.6 | 1 |  | 0
KT-015 | Motor auf u. ab | 1 | 6 | 1 | 5 | 0
KT-016 | Wiegebalken | 1 | 6 | 1 | 5 | 0
KT-017 | Igus-Schiene | 1 | 6 | 6 |  | 0
KT-018 | Igus-Schlitten | 2 | 12 | 14 |  | 0
KT-019 | Servo klein | 1 | 6 | 10 |  | 0
KT-020 | Servo groß | 1 | 6 | 2 | 4 | 0
KT-021 | Energiekette | 1 | 6 | 2 | 4 | 0
KT-022 | Raspberry Pi | 1 | 6 | 1 |  | 5 | Jeder einzeln
KT-023 | Touchscreen | 1 | 6 | 1 |  | 5 | Jeder einzeln
KT-024 | Netzteil | 1 | 6 | 1 |  | 5 | Jeder einzeln
KT-025 | Abdeckblech | 1 | 6 | 6 |  | 0 | Nils
KT-027 | PMMA | 1 | 6 | 7 |  | 0
KT-028 | SD-Karte | 1 | 6 | 1 |  | 5 | Jeder einzeln
KT-029 | Motor Crusher | 1 | 6 | 6 |  | 0
KT-030 | Eiscrusher | 1 | 6 | 6 | 0 | 0
KT-050 | DIN 912 M3x30 | 24 | 144 |  |  | 144
KT-051 | Mutter M3 | 43 | 258 |  |  | 258
KT-052 | DIN 912 M4x14 | 24 | 144 |  |  | 144
KT-053 | Unterlegscheibe A4,3 | 29 | 174 |  |  | 174
KT-054 | Nutenstein M4 | 3 | 18 |  |  | 18
KT-055 | Hammerkopf Mutter M4 | 26 | 156 |  |  | 156
KT-056 | DIN 912 M3x6 | 20 | 120 |  |  | 120
KT-057 | DIN 912 M5x25 | 3 | 18 |  |  | 18
KT-058 | Mutter M5 | 6 | 36 |  |  | 36
KT-059 | Unterlegscheibe A5,3 | 14 | 84 |  |  | 84
KT-060 | Karosseriescheibe M5 | 1 | 6 |  |  | 6
KT-061 | DIN 7991 M5x30 | 1 | 6 |  |  | 6
KT-062 | DIN 912 M3x10 | 7 | 42 |  |  | 42
KT-063 | Unterlegscheibe A3,2 | 8 | 48 |  |  | 48
KT-064 | DIN 7991 M3x8 | 8 | 48 |  |  | 48
KT-065 | DIN 7991 M4x18 | 3 | 18 |  |  | 18
KT-066 | DIN 7991 M4x12 | 1 | 6 |  |  | 6
KT-067 | Nutenstein M3 | 4 | 24 |  |  | 24
KT-068 | Flanschkopfschraube M5x16 | 7 | 42 |  |  | 42
KT-069 | DIN 912 M4x10 | 5 | 30 |  |  | 30
KT-070 | DIN 7991 M3x10 | 2 | 12 |  |  | 12
KT-071 | DIN 912 M5x10 | 8 | 48 |  |  | 48
KT-072 | Nutenstein M5 | 8 | 48 |  |  | 48
KT-073 | DIN 912 M2x20 | 6 | 36 |  |  | 36
KT-074 | Mutter M2 | 6 | 36 |  |  | 36
KT-075 | DIN 7991 M3x12 | 2 | 12 |  |  | 12
KT-076 | DIN 912 M3x20 | 2 | 12 |  |  | 12
KT-077 | Hammerkopf Mutter M3 | 1 | 6 |  |  | 6
KT-078 | Gewindestift M3x5 | 1 | 6 |  |  | 6
KT-999 | Dummy | 0 | 0 |  |  | 0

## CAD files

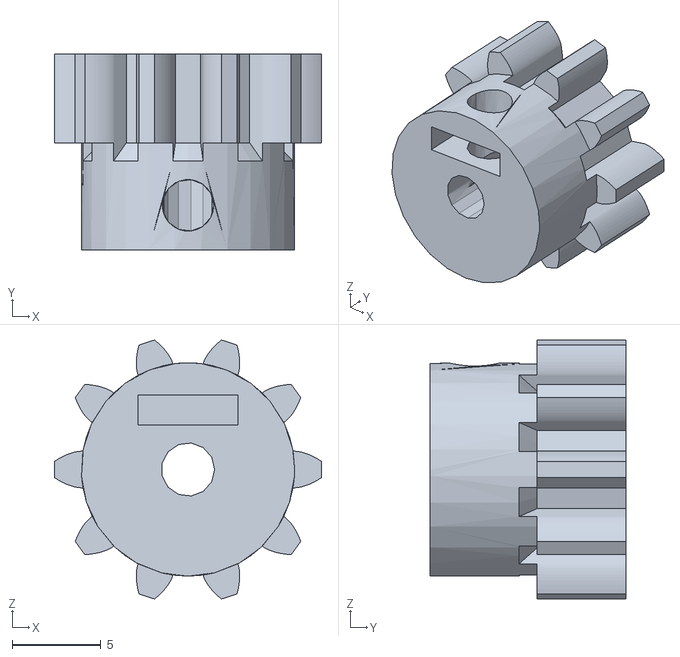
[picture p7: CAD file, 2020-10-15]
CAD/stl/DT-020_Zahnrad.stl
15.0 x 11.0 x 14.6

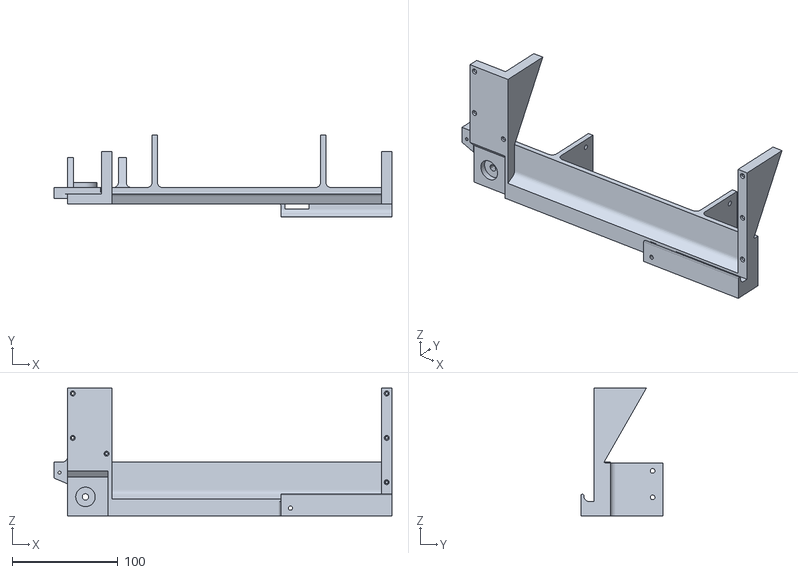
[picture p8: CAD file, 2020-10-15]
CAD/stl/DT-024_Strohhalmmagazin .stl
319.8 x 78.0 x 120.8

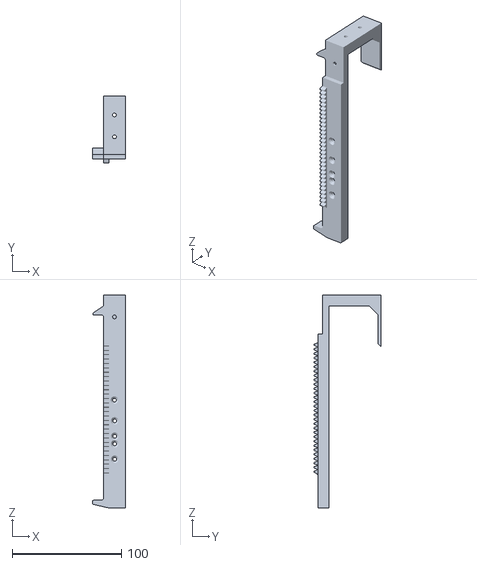
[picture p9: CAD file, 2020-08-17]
CAD/stl/DT-022_Zahnstange Rührer.stl
30.0 x 61.4 x 194.5

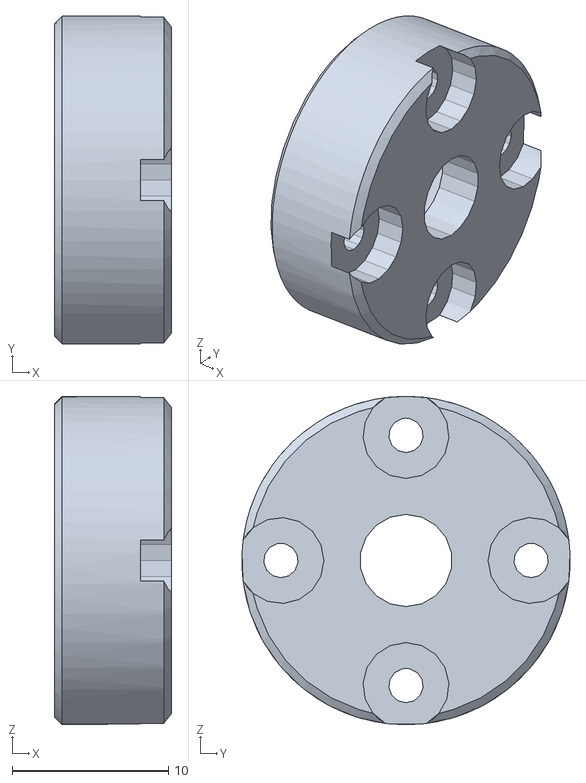
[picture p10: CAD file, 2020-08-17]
CAD/stl/DT-027_Verbindung Servo zu Schraube.stl
7.50 x 21.0 x 21.0

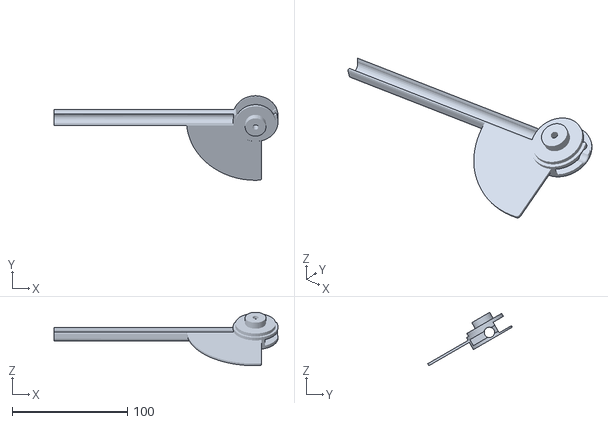
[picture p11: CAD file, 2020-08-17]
CAD/stl/DT-028_Drehbarer Arm.stl
194.5 x 73.5 x 46.4

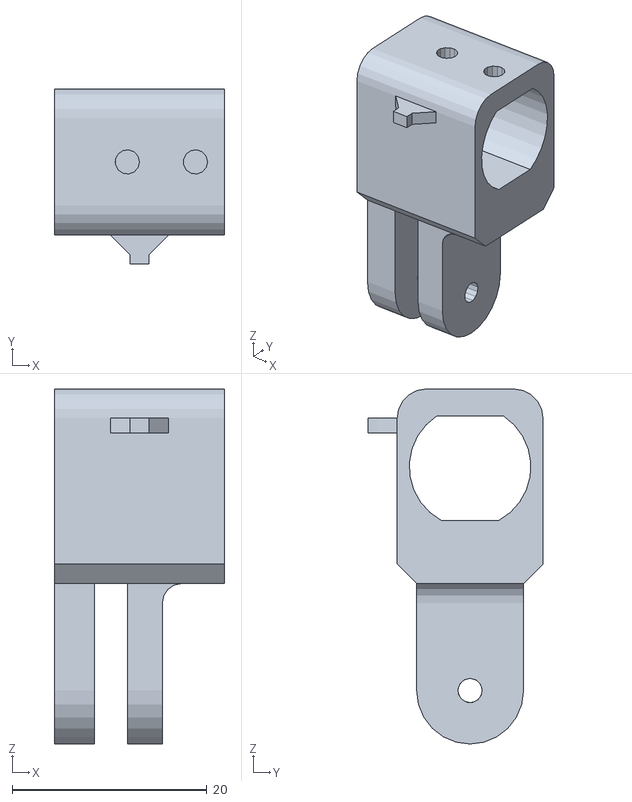
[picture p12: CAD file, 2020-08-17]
CAD/stl/DT-026_Motorhalterung Reibrad.stl
17.5 x 18.0 x 36.5

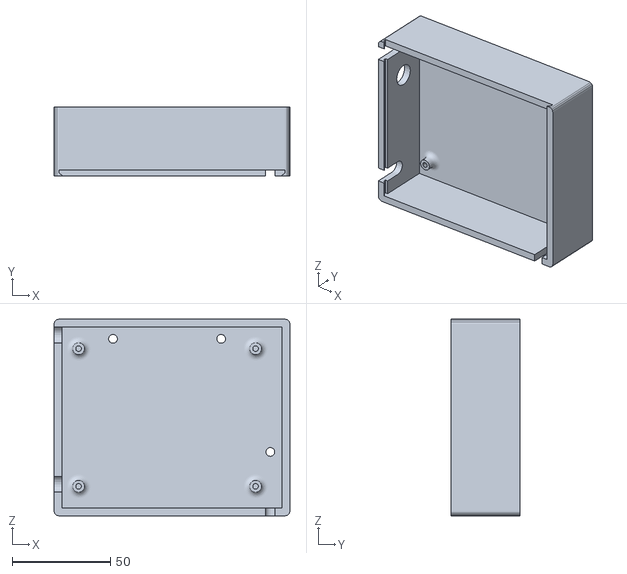
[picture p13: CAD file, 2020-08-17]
CAD/stl/DT-003_Box Hauptplatine.stl
120.0 x 35.0 x 100.0

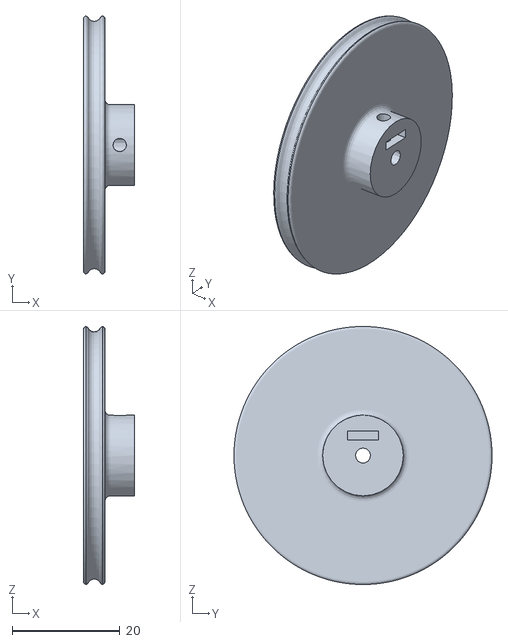
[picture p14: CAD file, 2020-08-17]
CAD/stl/DT-025_Reibrad.stl
9.50 x 48.0 x 48.0

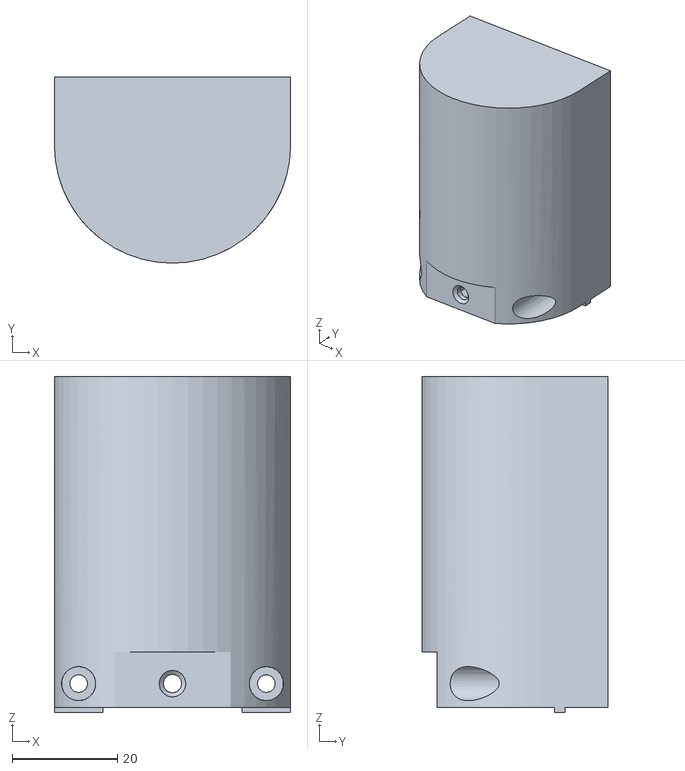
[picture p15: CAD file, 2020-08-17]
CAD/stl/DT-005_Klemme Pumpenhalterung.stl
45.0 x 35.5 x 64.0

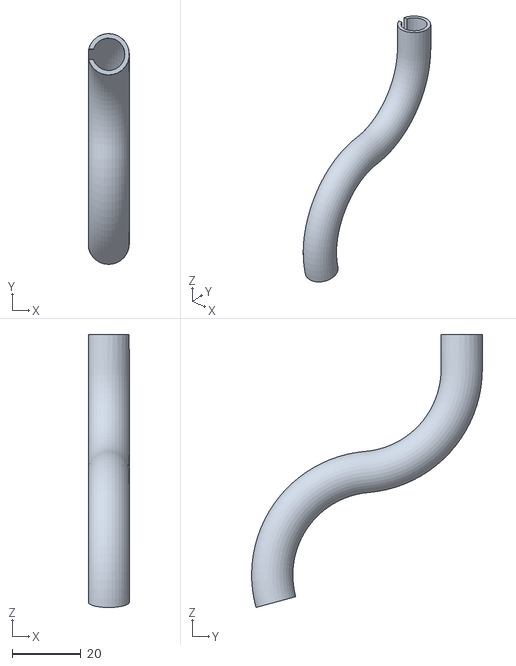
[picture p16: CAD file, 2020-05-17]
CAD/stl/DT-015_Schlauchführung.stl
11.8 x 67.0 x 79.2

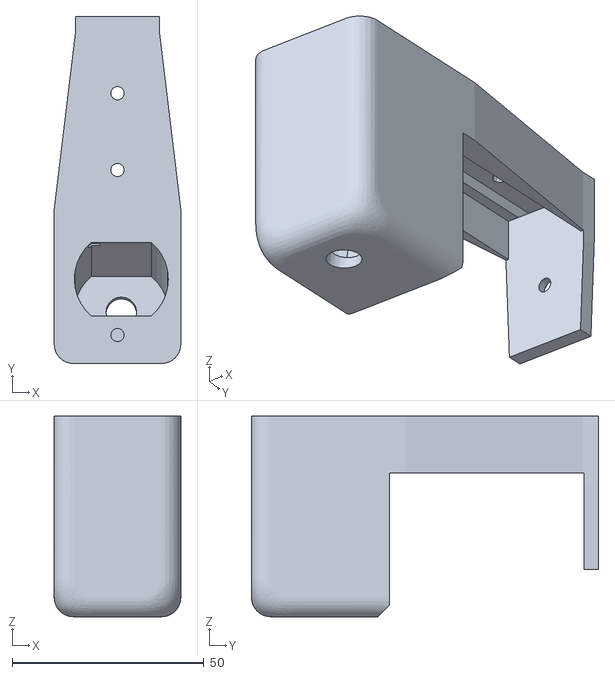
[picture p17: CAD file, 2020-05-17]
CAD/stl/DT-023_Halterung Rührermotor.stl
33.0 x 90.4 x 52.3

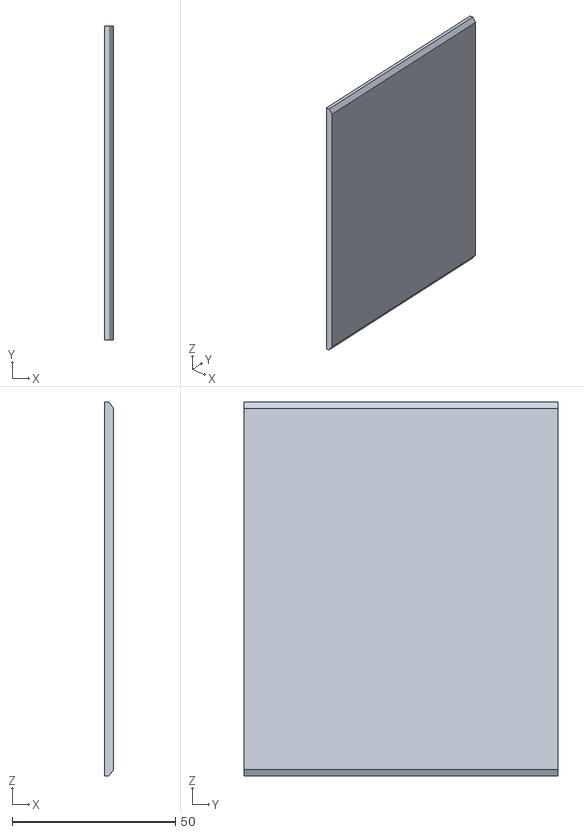
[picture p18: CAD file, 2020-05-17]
CAD/stl/DT-004_Deckel Hauptplatine.stl
2.90 x 96.0 x 114.5

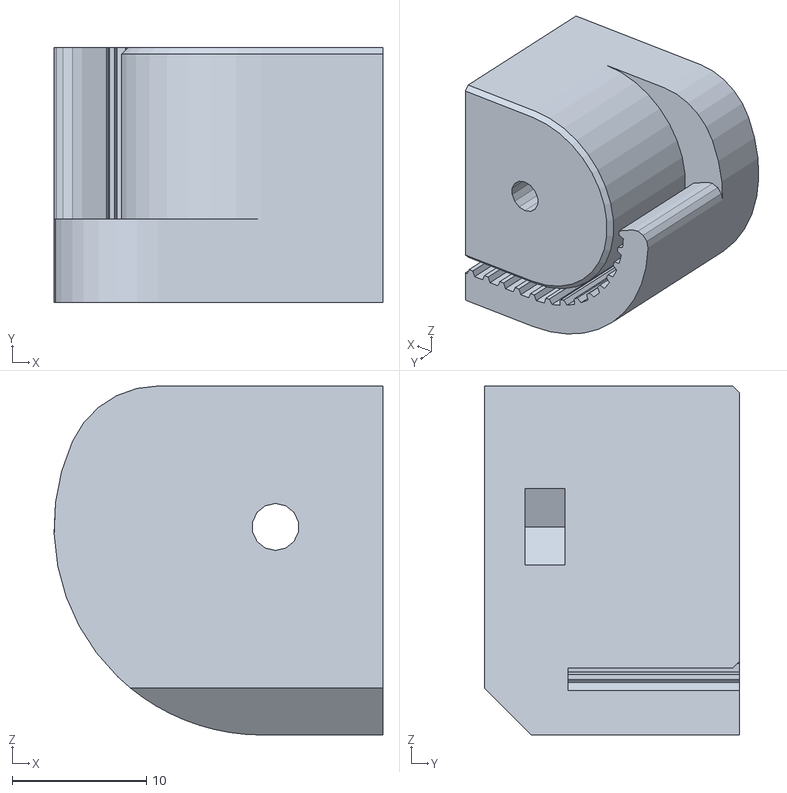
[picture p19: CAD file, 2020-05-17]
CAD/stl/DT-011_Riemenbefestigung_links.stl
24.5 x 19.0 x 26.0

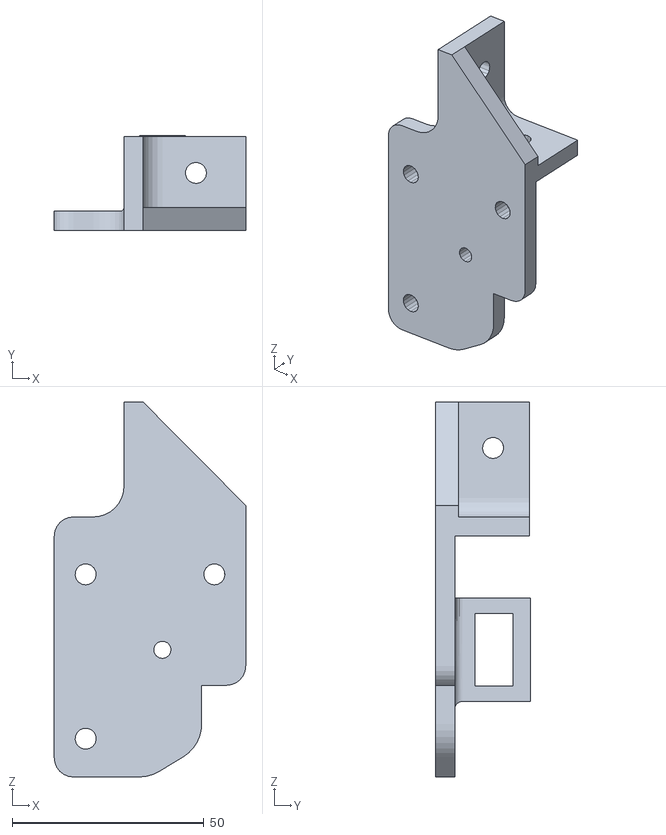
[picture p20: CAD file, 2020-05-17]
CAD/stl/DT-002_Riemenumlenkung.stl
50.0 x 24.8 x 97.9

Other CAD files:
CAD/stl/DT-009_Teller_Teil3.stl
CAD/stl/DT-010_Riemenbefestigung_rechts.stl
CAD/stl/DT-001_Schrittmotorhalter.stl
CAD/stl/DT-012_Abdeckplatte Rührermotor.stl
CAD/par/Abwicklung für KT-026 Abdeckblech Pumpen.psm
CAD/par/KT-025_Abdeckblech oben.psm
CAD/par/KT-026_Abeckblech Pumpen.psm
CAD/par/KT-080_Abdeckblech Strohhalmmagazin vorne .psm
CAD/par/KT-081_Abdeckblech Strohhalmmagazin hinten .psm
CAD/par/KT-083_Knotenblech .psm
CAD/par/KT-088_Crusher Blech1.psm
CAD/stl/DT-006_Pumpenhalterung.stl
CAD/stl/DT-007_Teller_Teil1.stl
CAD/stl/DT-008_Teller_Teil2.stl
CAD/stl/DT-013_Box Wiegeplatine.stl
CAD/stl/DT-014_Deckel Wiegeplatine.stl
CAD/stl/DT-016_Box Rührerplatine.stl
CAD/stl/DT-017_Deckel Rührerplatine.stl
CAD/stl/DT-018_Grundplatte Rührer.stl
CAD/stl/DT-019_Motorklemme.stl

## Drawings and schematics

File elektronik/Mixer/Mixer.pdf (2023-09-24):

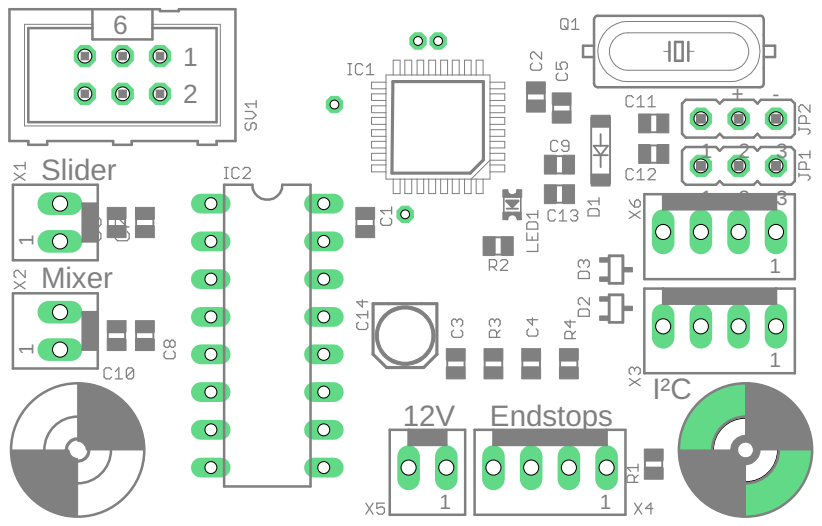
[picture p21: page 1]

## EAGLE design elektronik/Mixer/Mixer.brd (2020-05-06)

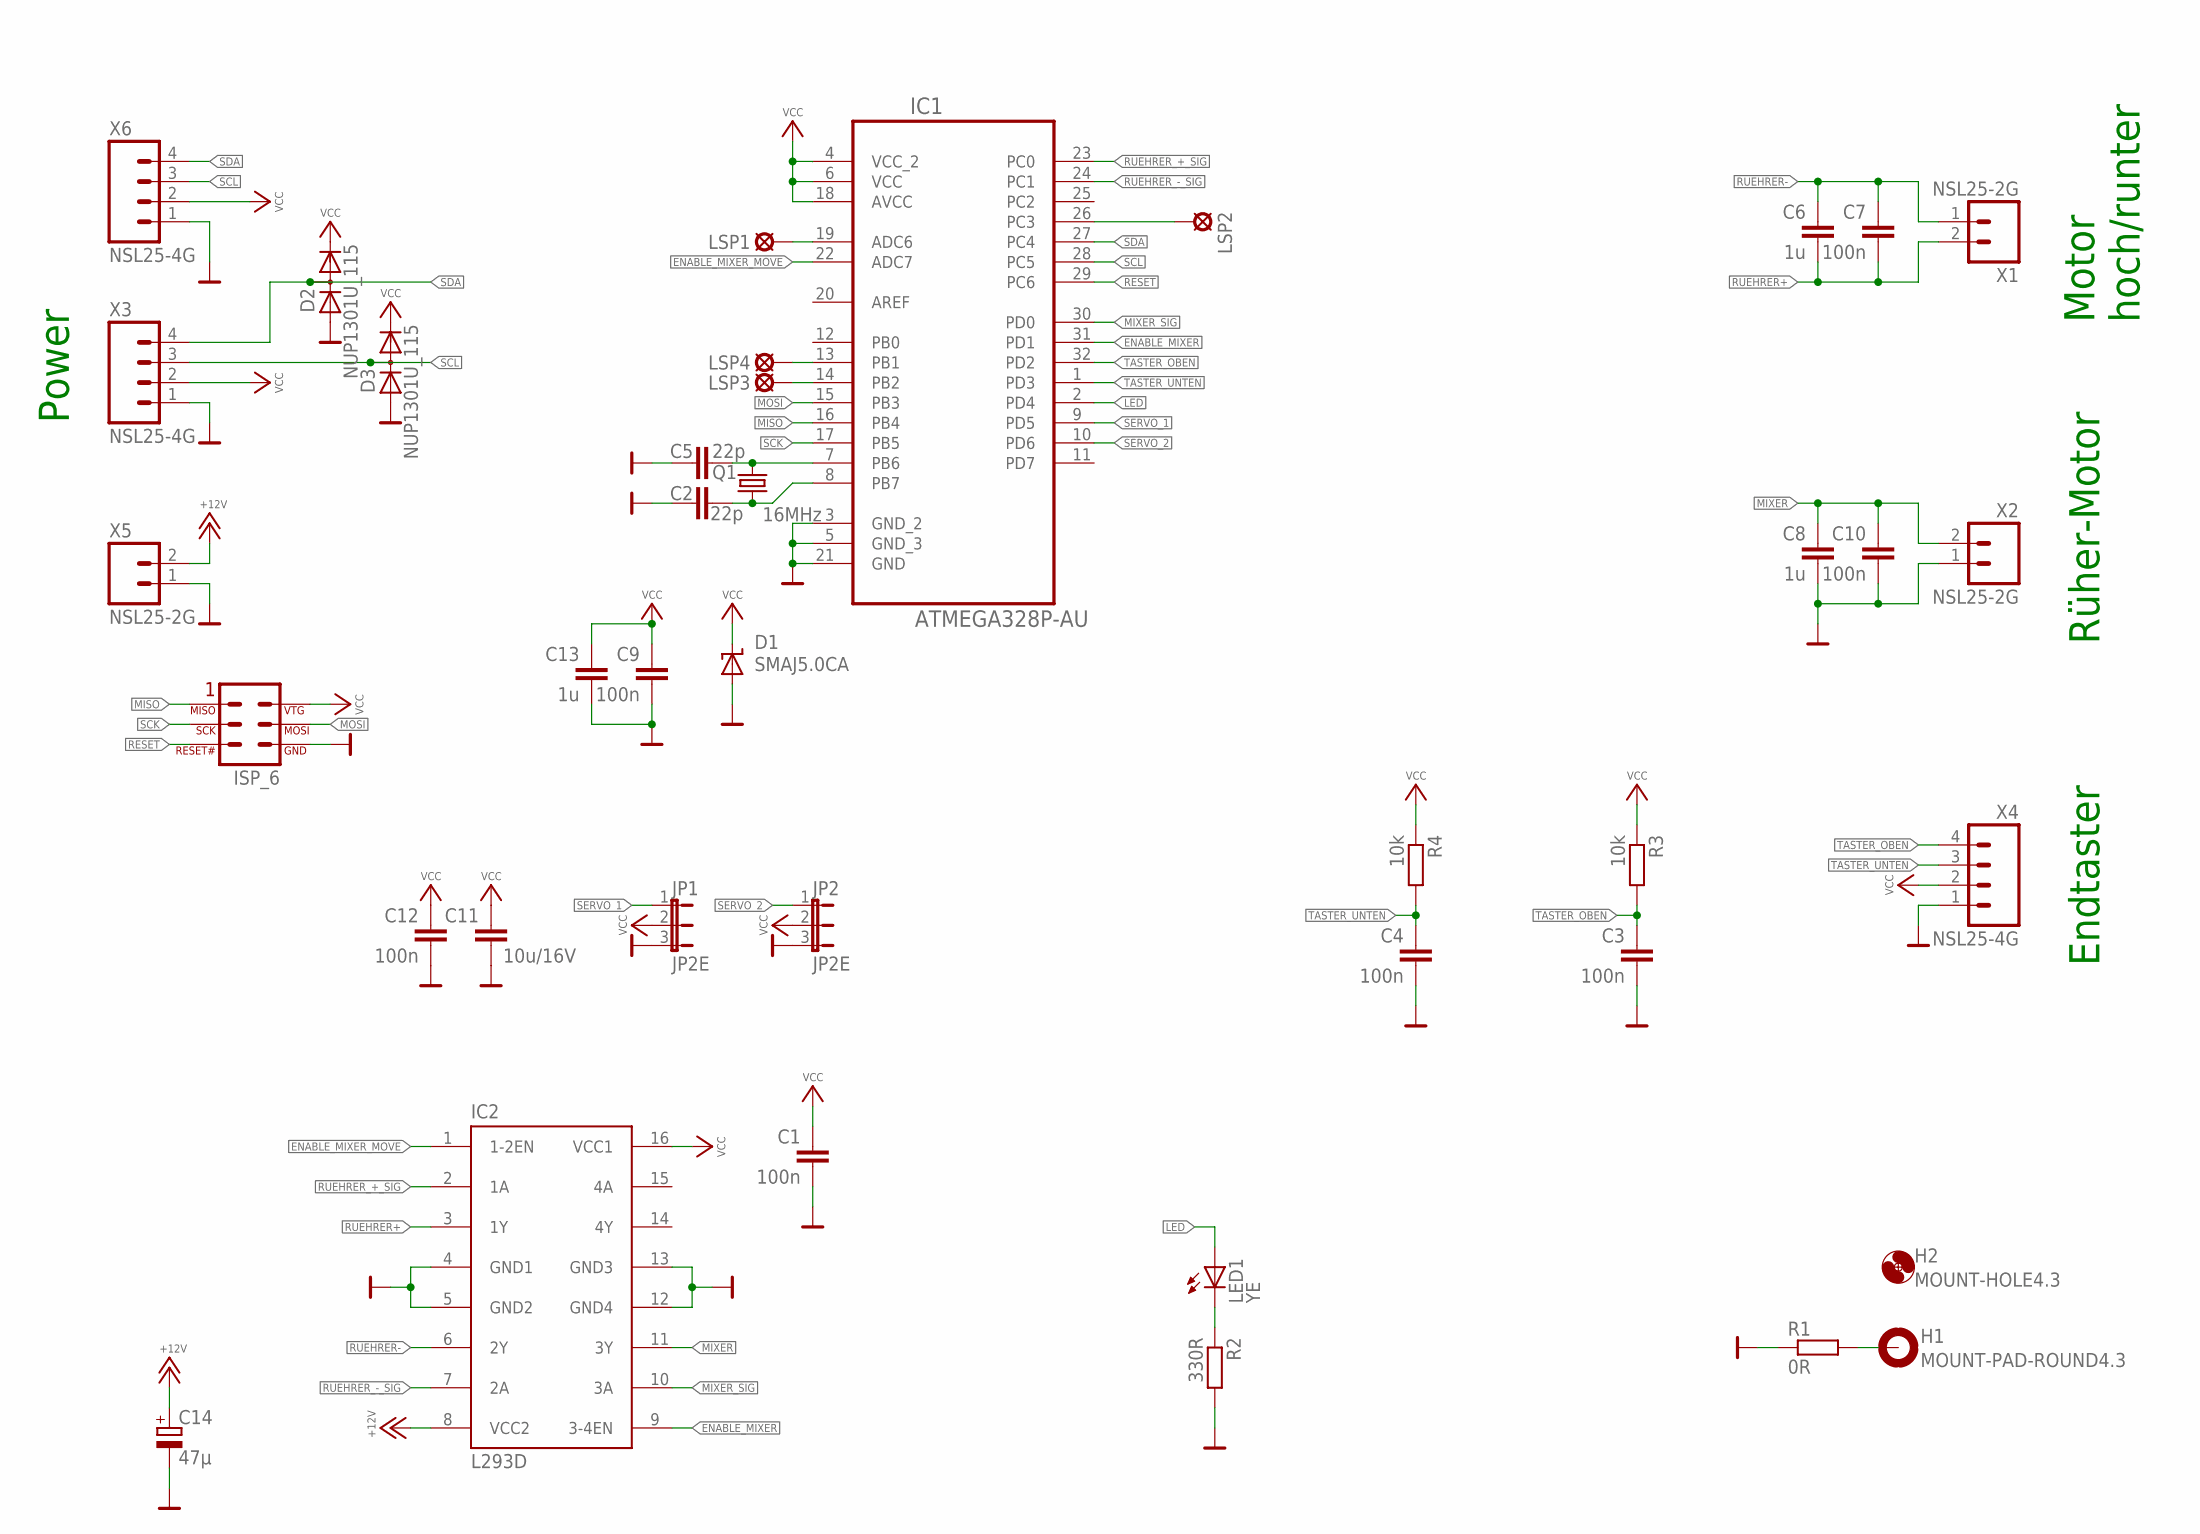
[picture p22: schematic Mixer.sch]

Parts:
C1, C3, C4, C7, C9, C10, C12: 100n; 0805CRH
C2, C5: 22p; 0805CRH
C6, C8, C13: 1u; 0805CRH
C11: 10u/16V; 0805CRH
C14: 47µ; 153CLV-0405
D1: SMAJ5.0CA; SMA-DO214AC
D2, D3: NUP1301U_115; SOT323-3
H1: MOUNT-PAD-ROUND4.3; 4,3-PAD
H2: MOUNT-HOLE4.3; 4,3
IC1: ATMEGA328P-AU; QFP80P900X900X120-32N
IC2: L293D; DIL16
JP1, JP2: JP2E; JP2
LED1: YE; CHIPLED_0805
LSP1, LSP2, LSP3, LSP4: LSP06
Q1: 16MHz; HC49UP
R1: 0R; 0805CRH
R2: 330R; 0805CRH
R3, R4: 10k; 0805CRH
SV1: ATMEL_ISP_6; ML6
X1, X2, X5: NSL25-2G
X3, X4, X6: NSL25-4G

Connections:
+12V: C14.+, IC2.8 (VCC2), X5.2
ADC6: IC1.19 (ADC6), LSP1.MP
ENABLE_MIXER: IC1.31 (PD1), IC2.9 (3-4EN)
ENABLE_MIXER_MOVE: IC1.22 (ADC7), IC2.1 (1-2EN)
GND: C1.2, C2.1, C3.2, C4.2, C5.1, C8.2, C9.2, C10.2, C11.2, C12.2, C13.2, C14.-, D1.A, D2.1, D3.1, IC1.3 (GND_2), IC1.5 (GND_3), IC1.21 (GND), IC2.4 (GND1), IC2.5 (GND2), IC2.12 (GND4), IC2.13 (GND3), JP1.3, JP2.3, R1.1, R2.2, SV1.6, X2.1, X3.1, X4.1, X5.1, X6.1
LED: IC1.2 (PD4), LED1.A
MISO: IC1.16 (PB4), SV1.1
MIXER: C8.1, C10.1, IC2.11 (3Y), X2.2
MIXER_SIG: IC1.30 (PD0), IC2.10 (3A)
MOSI: IC1.15 (PB3), SV1.4
unnamed: H1.B4,3, R1.2
unnamed: LED1.C, R2.1
unnamed: IC1.26 (PC3), LSP2.MP
unnamed: C5.2, IC1.7 (PB6), Q1.2
unnamed: C2.2, IC1.8 (PB7), Q1.1
unnamed: IC1.14 (PB2), LSP3.MP
unnamed: IC1.13 (PB1), LSP4.MP
RESET: IC1.29 (PC6), SV1.5
RUEHRER+: C6.2, C7.2, IC2.3 (1Y), X1.2
RUEHRER-: C6.1, C7.1, IC2.6 (2Y), X1.1
RUEHRER_+_SIG: IC1.23 (PC0), IC2.2 (1A)
RUEHRER_-_SIG: IC1.24 (PC1), IC2.7 (2A)
SCK: IC1.17 (PB5), SV1.3
SCL: D3.3, IC1.28 (PC5), X3.3, X6.3
SDA: D2.3, IC1.27 (PC4), X3.4, X6.4
SERVO_1: IC1.9 (PD5), JP1.1
SERVO_2: IC1.10 (PD6), JP2.1
TASTER_OBEN: C3.1, IC1.32 (PD2), R3.2, X4.4
TASTER_UNTEN: C4.1, IC1.1 (PD3), R4.2, X4.3
VCC: C1.1, C9.1, C11.1, C12.1, C13.1, D1.K (C), D2.2, D3.2, IC1.4 (VCC_2), IC1.6 (VCC), IC1.18 (AVCC), IC2.16 (VCC1), JP1.2, JP2.2, R3.1, R4.1, SV1.2, X3.2, X4.2, X6.2

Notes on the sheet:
Power
Rüher-Motor
Endtaster
Motor hoch/runter

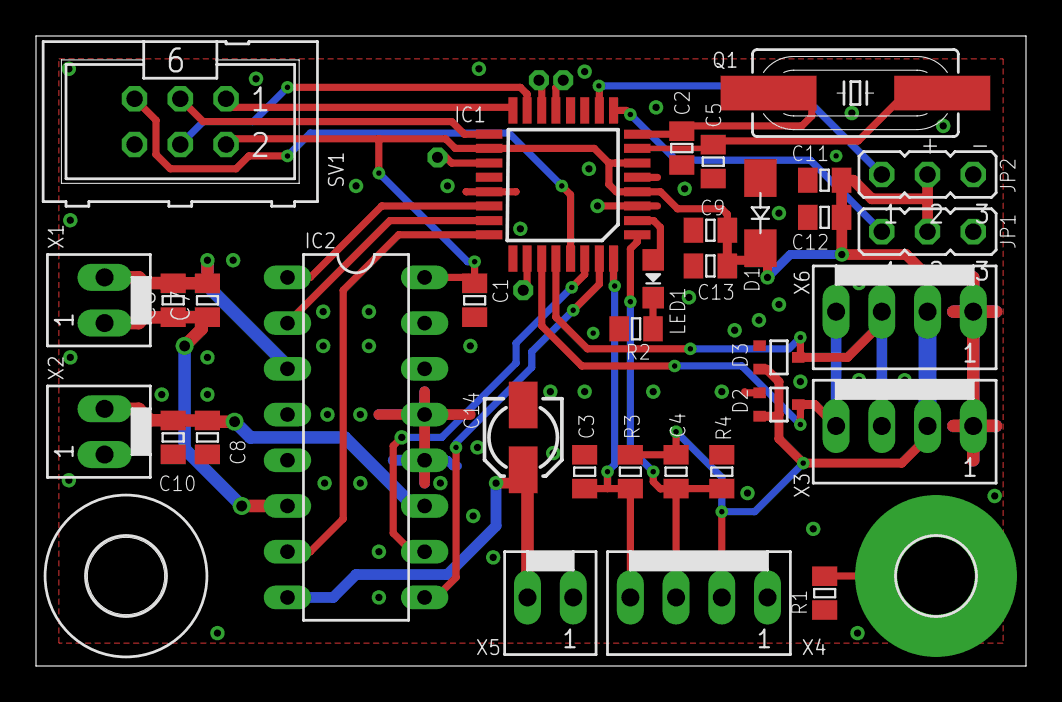
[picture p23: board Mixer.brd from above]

Board: 2 copper layers, 55.0 x 35.0 mm, 40 parts (0 on the bottom side), 30 nets.

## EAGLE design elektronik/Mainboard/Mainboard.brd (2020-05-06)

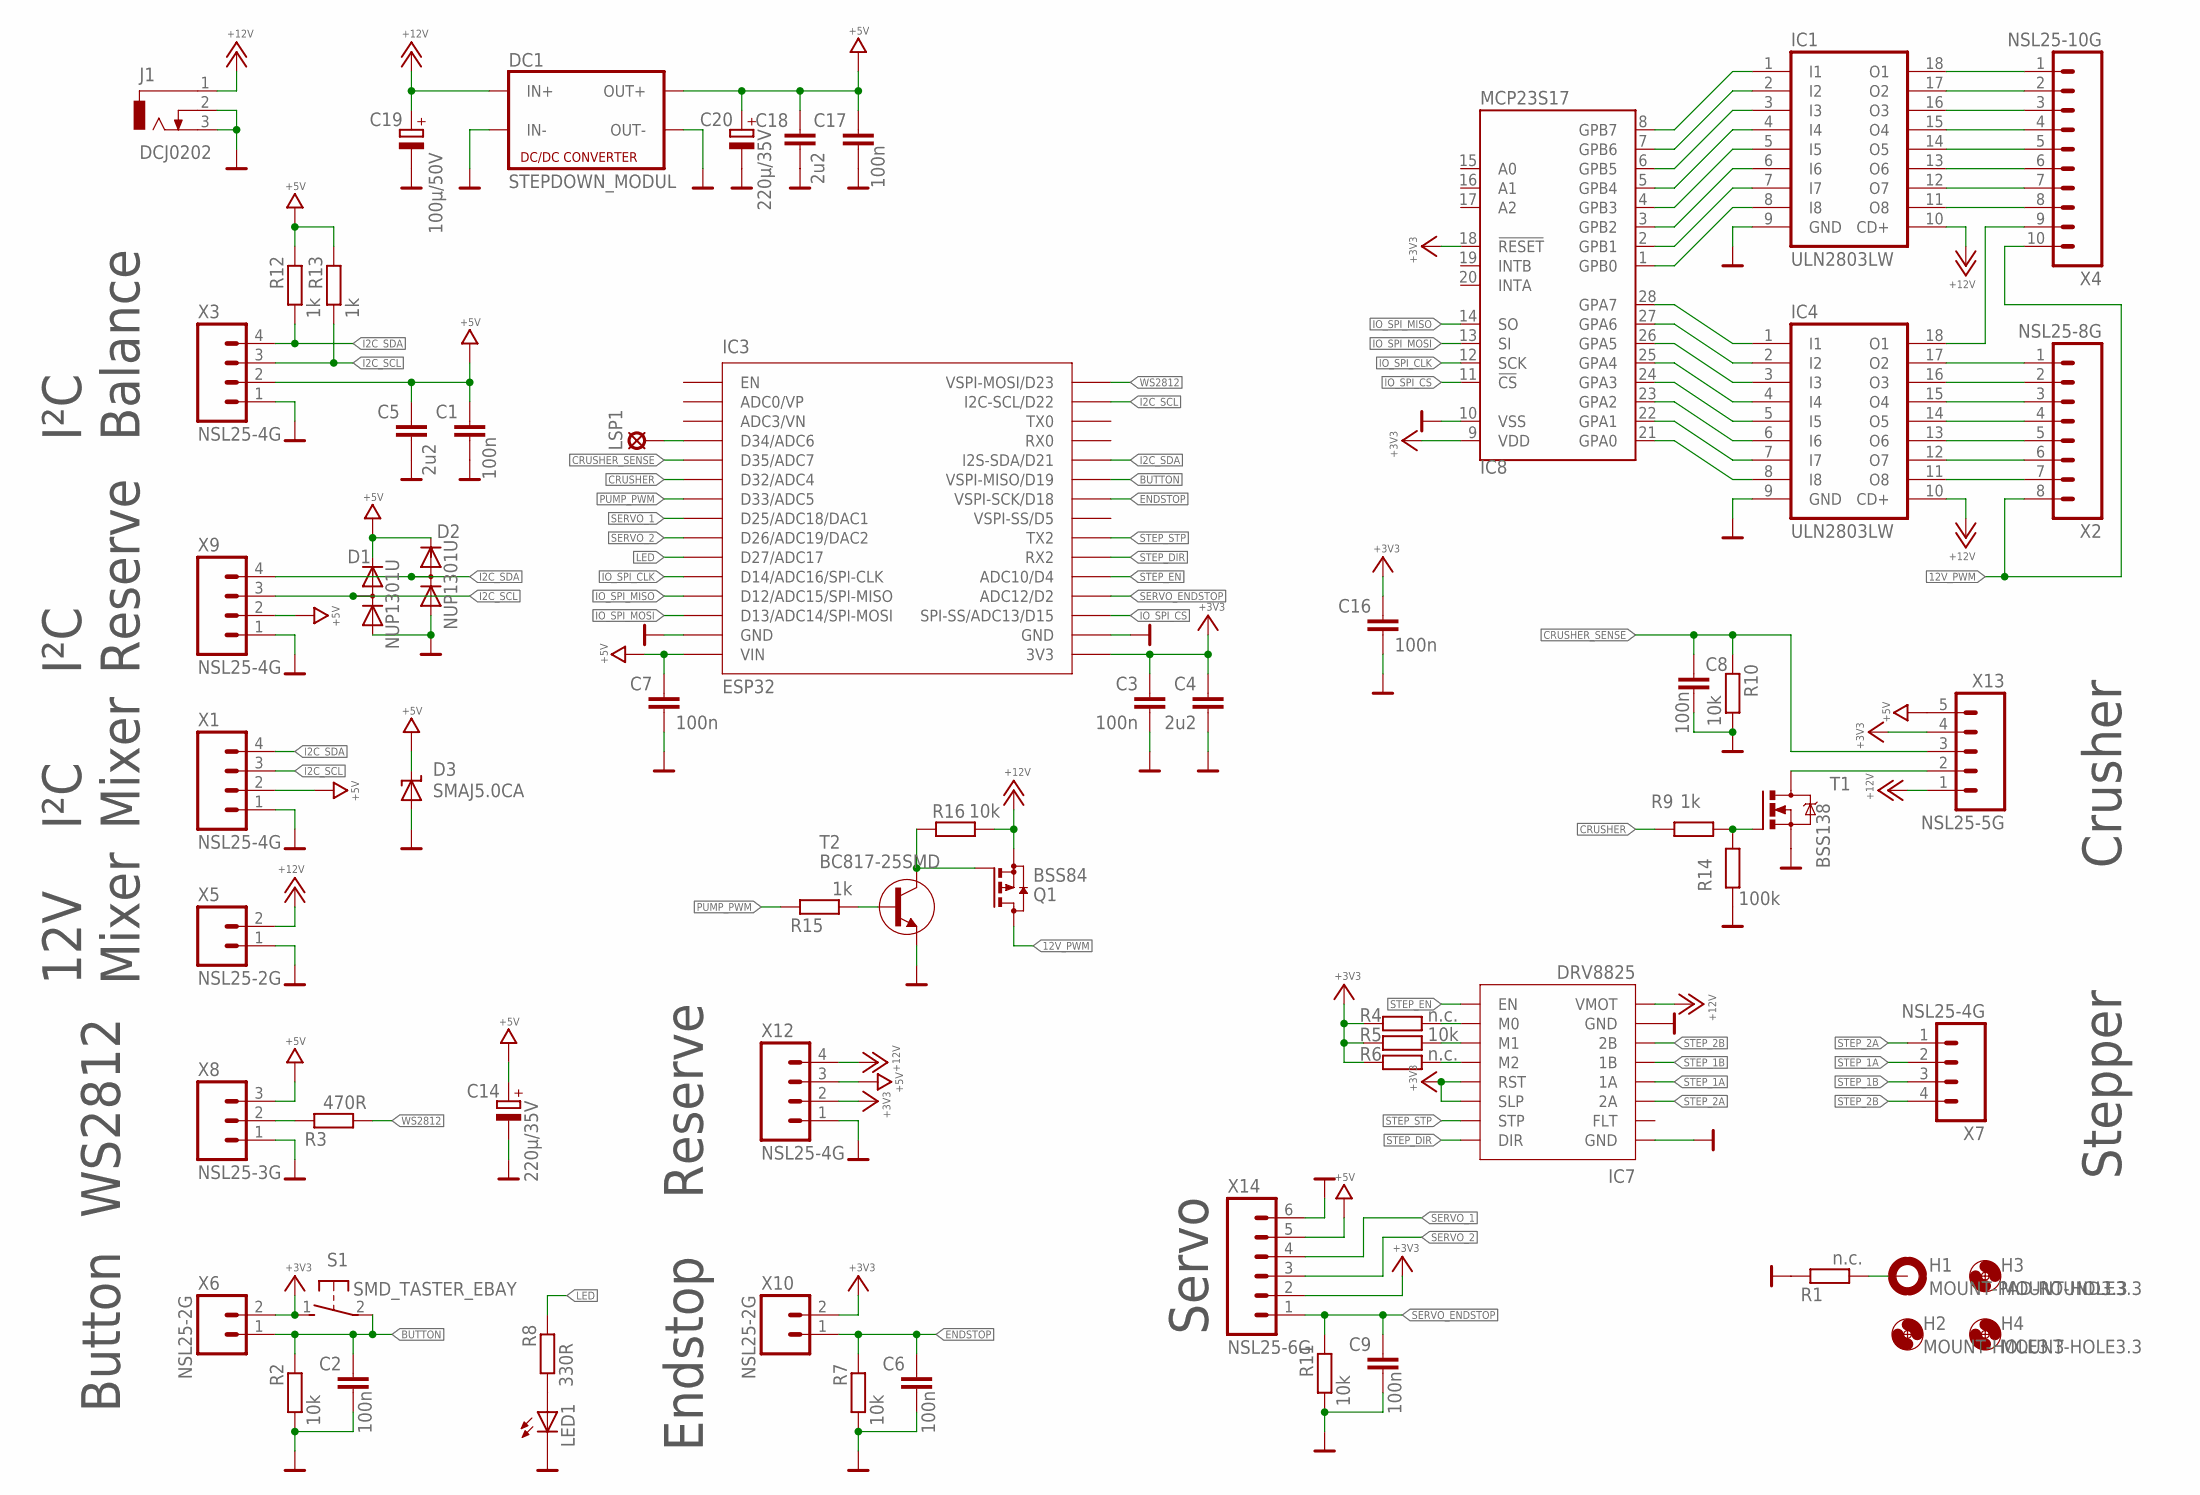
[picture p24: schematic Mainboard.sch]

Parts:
C1, C2, C3, C6, C7, C8, C9, C16, C17: 100n; 0805CRH
C4, C5, C18: 2u2; 0805CRH
C14, C20: 220µ/35V; 153CLV-1010
C19: 100µ/50V; 153CLV-1010
D1, D2: NUP1301U; SOT323-3
D3: SMAJ5.0CA; SMA-DO214AC
DC1: STEPDOWN_MODUL
H1: MOUNT-PAD-ROUND3.3; 3,3-PAD
H2, H3, H4: MOUNT-HOLE3.3; 3,3
IC1, IC4: ULN2803LW; SO18W
IC3: ESP32
IC7: DRV8825
IC8: MCP23S17; SOIC-28
J1: DCJ0202
LED1: LEDCHIPLED_0805; CHIPLED_0805
LSP1: LSP06
Q1: BSS84; SOT23
R1, R4, R6: n.c.; 0805CRH
R2, R5, R7, R10, R11, R16: 10k; 0805CRH
R3: 470R; 0805CRH
R8: 330R; 0805CRH
R9, R12, R13, R15: 1k; 0805CRH
R14: 100k; 0805CRH
S1: SMD_TASTER_EBAY; DTSM3XN
T1: BSS138; SOT23
T2: BC817-25SMD; SOT23-BEC
X1, X3, X7, X9, X12: NSL25-4G
X2: NSL25-8G
X4: NSL25-10G
X5, X6, X10: NSL25-2G
X8: NSL25-3G
X13: NSL25-5G
X14: NSL25-6G

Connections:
12V_PWM: Q1.3 (D), X2.8, X4.10
+3V3: C3.1, C4.1, C16.1, IC3.3V3, IC7.RST, IC7.SLP, IC8.9 (VDD), IC8.18 (!RESET!), R4.1, R5.1, R6.1, S1.1 (S), X6.2, X10.2, X12.2, X13.4, X14.2
+5V: C1.1, C5.1, C7.1, C14.+, C17.1, C18.1, C20.+, D1.2, D2.2, D3.K (C), DC1.OUT+, IC3.VIN, R12.1, R13.1, X1.2, X3.2, X8.3, X9.2, X12.3, X13.5, X14.5
+12V: C19.+, DC1.IN+, IC1.10 (CD+), IC4.10 (CD+), IC7.VMOT, J1.1, Q1.2 (S), R16.2, X5.2, X12.4, X13.1
ADC3/VN: IC3.VN (ADC3/VN)
BUTTON: C2.1, IC3.D19 (VSPI-MISO/D19), R2.1, S1.2, X6.1
CRUSHER: IC3.D32 (D32/ADC4), R9.1
CRUSHER_SENSE: C8.1, IC3.D35 (D35/ADC7), R10.1, X13.3
ENDSTOP: C6.1, IC3.D18 (VSPI-SCK/D18), R7.1, X10.1
GND: C1.2, C2.2, C3.2, C4.2, C5.2, C6.2, C7.2, C8.2, C9.2, C14.-, C16.2, C17.2, C18.2, C19.-, C20.-, D1.1, D2.1, D3.A, DC1.IN-, DC1.OUT-, IC1.9 (GND), IC3.GND@1 (GND), IC3.GND@2 (GND), IC4.9 (GND), IC7.GND@1 (GND), IC7.GND@2 (GND), IC8.10 (VSS), J1.2, J1.3, LED1.C, R1.1, R2.2, R7.2, R10.2, R11.2, R14.1, T1.2 (S), T2.E, X1.1, X3.1, X5.1, X8.1, X9.1, X12.1, X14.6
I2C_SCL: D1.3, IC3.D22 (I2C-SCL/D22), R13.2, X1.3, X3.3, X9.3
I2C_SDA: D2.3, IC3.D21 (I2S-SDA/D21), R12.2, X1.4, X3.4, X9.4
IO_SPI_CLK: IC3.D14 (D14/ADC16/SPI-CLK), IC8.12 (SCK)
IO_SPI_CS: IC3.D15 (SPI-SS/ADC13/D15), IC8.11 (!CS!)
IO_SPI_MISO: IC3.D12 (D12/ADC15/SPI-MISO), IC8.14 (SO)
IO_SPI_MOSI: IC3.D13 (D13/ADC14/SPI-MOSI), IC8.13 (SI)
LED: IC3.D27 (D27/ADC17), R8.1
unnamed: LED1.A, R8.2
unnamed: T1.3 (D), X13.2
unnamed: R9.2, R14.2, T1.1 (G)
unnamed: Q1.1 (G), R16.1, T2.C
unnamed: R15.2, T2.B
unnamed: IC3.D34 (D34/ADC6), LSP1.MP
unnamed: R3.1, X8.2
unnamed: H1.B3,3, R1.2
unnamed: IC4.8 (I8), IC8.21 (GPA0)
unnamed: IC4.7 (I7), IC8.22 (GPA1)
unnamed: IC4.6 (I6), IC8.23 (GPA2)
unnamed: IC4.5 (I5), IC8.24 (GPA3)
unnamed: IC4.4 (I4), IC8.25 (GPA4)
unnamed: IC4.3 (I3), IC8.26 (GPA5)
unnamed: IC4.2 (I2), IC8.27 (GPA6)
unnamed: IC1.18 (O1), X4.1
unnamed: IC1.17 (O2), X4.2
unnamed: IC1.16 (O3), X4.3
unnamed: IC1.15 (O4), X4.4
unnamed: IC1.14 (O5), X4.5
unnamed: IC1.13 (O6), X4.6
unnamed: IC1.12 (O7), X4.7
unnamed: IC1.11 (O8), X4.8
unnamed: IC4.18 (O1), X4.9
unnamed: IC4.17 (O2), X2.1
unnamed: IC4.16 (O3), X2.2
unnamed: IC4.15 (O4), X2.3
unnamed: IC4.14 (O5), X2.4
unnamed: IC4.13 (O6), X2.5
unnamed: IC4.12 (O7), X2.6
unnamed: IC4.11 (O8), X2.7
unnamed: IC4.1 (I1), IC8.28 (GPA7)
unnamed: IC1.8 (I8), IC8.1 (GPB0)
unnamed: IC7.M0, R4.2
unnamed: IC7.M1, R5.2
unnamed: IC7.M2, R6.2
unnamed: IC1.7 (I7), IC8.2 (GPB1)
unnamed: IC1.6 (I6), IC8.3 (GPB2)
unnamed: IC1.5 (I5), IC8.4 (GPB3)
unnamed: IC1.4 (I4), IC8.5 (GPB4)
unnamed: IC1.3 (I3), IC8.6 (GPB5)
unnamed: IC1.2 (I2), IC8.7 (GPB6)
unnamed: IC1.1 (I1), IC8.8 (GPB7)
PUMP_PWM: IC3.D33 (D33/ADC5), R15.1
SERVO_1: IC3.D25 (D25/ADC18/DAC1), X14.4
SERVO_2: IC3.D26 (D26/ADC19/DAC2), X14.3
SERVO_ENDSTOP: C9.1, IC3.D2 (ADC12/D2), R11.1, X14.1
STEP_1A: IC7.1A, X7.2
STEP_1B: IC7.1B, X7.3
STEP_2A: IC7.2A, X7.1
STEP_2B: IC7.2B, X7.4
STEP_DIR: IC3.RX2, IC7.DIR
STEP_EN: IC3.D4 (ADC10/D4), IC7.EN
STEP_STP: IC3.TX2, IC7.STP
WS2812: IC3.D23 (VSPI-MOSI/D23), R3.2

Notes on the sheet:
I²C Balance
I²C Mixer
12V Mixer
WS2812
I²C Reserve
Button
Endstop
Reserve
Stepper
Crusher
Servo

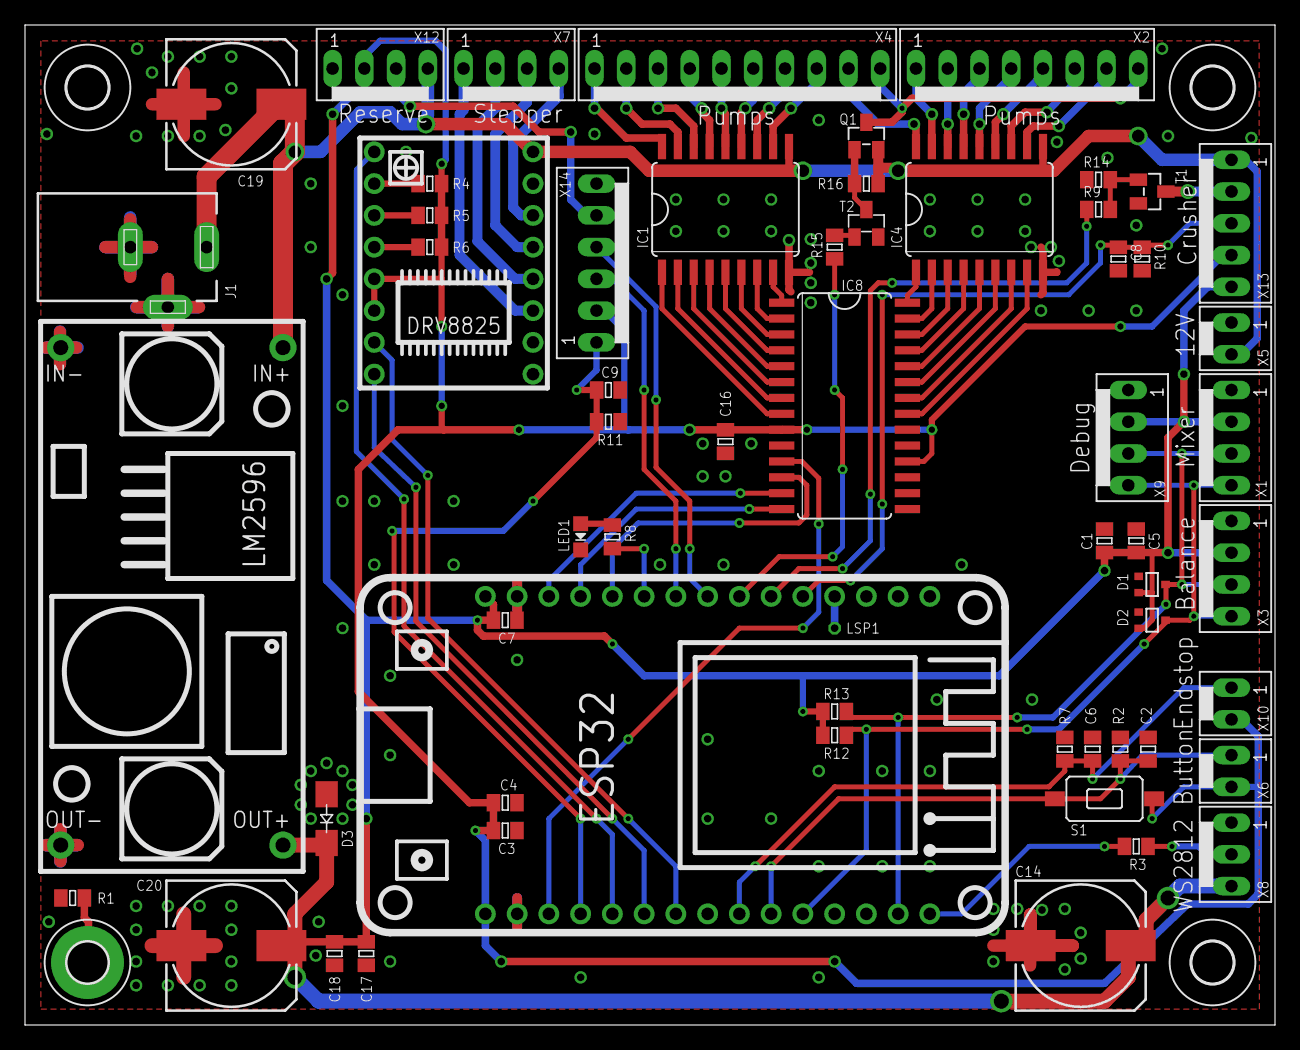
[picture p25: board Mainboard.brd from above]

Board: 2 copper layers, 100.0 x 80.0 mm, 64 parts (0 on the bottom side), 71 nets.

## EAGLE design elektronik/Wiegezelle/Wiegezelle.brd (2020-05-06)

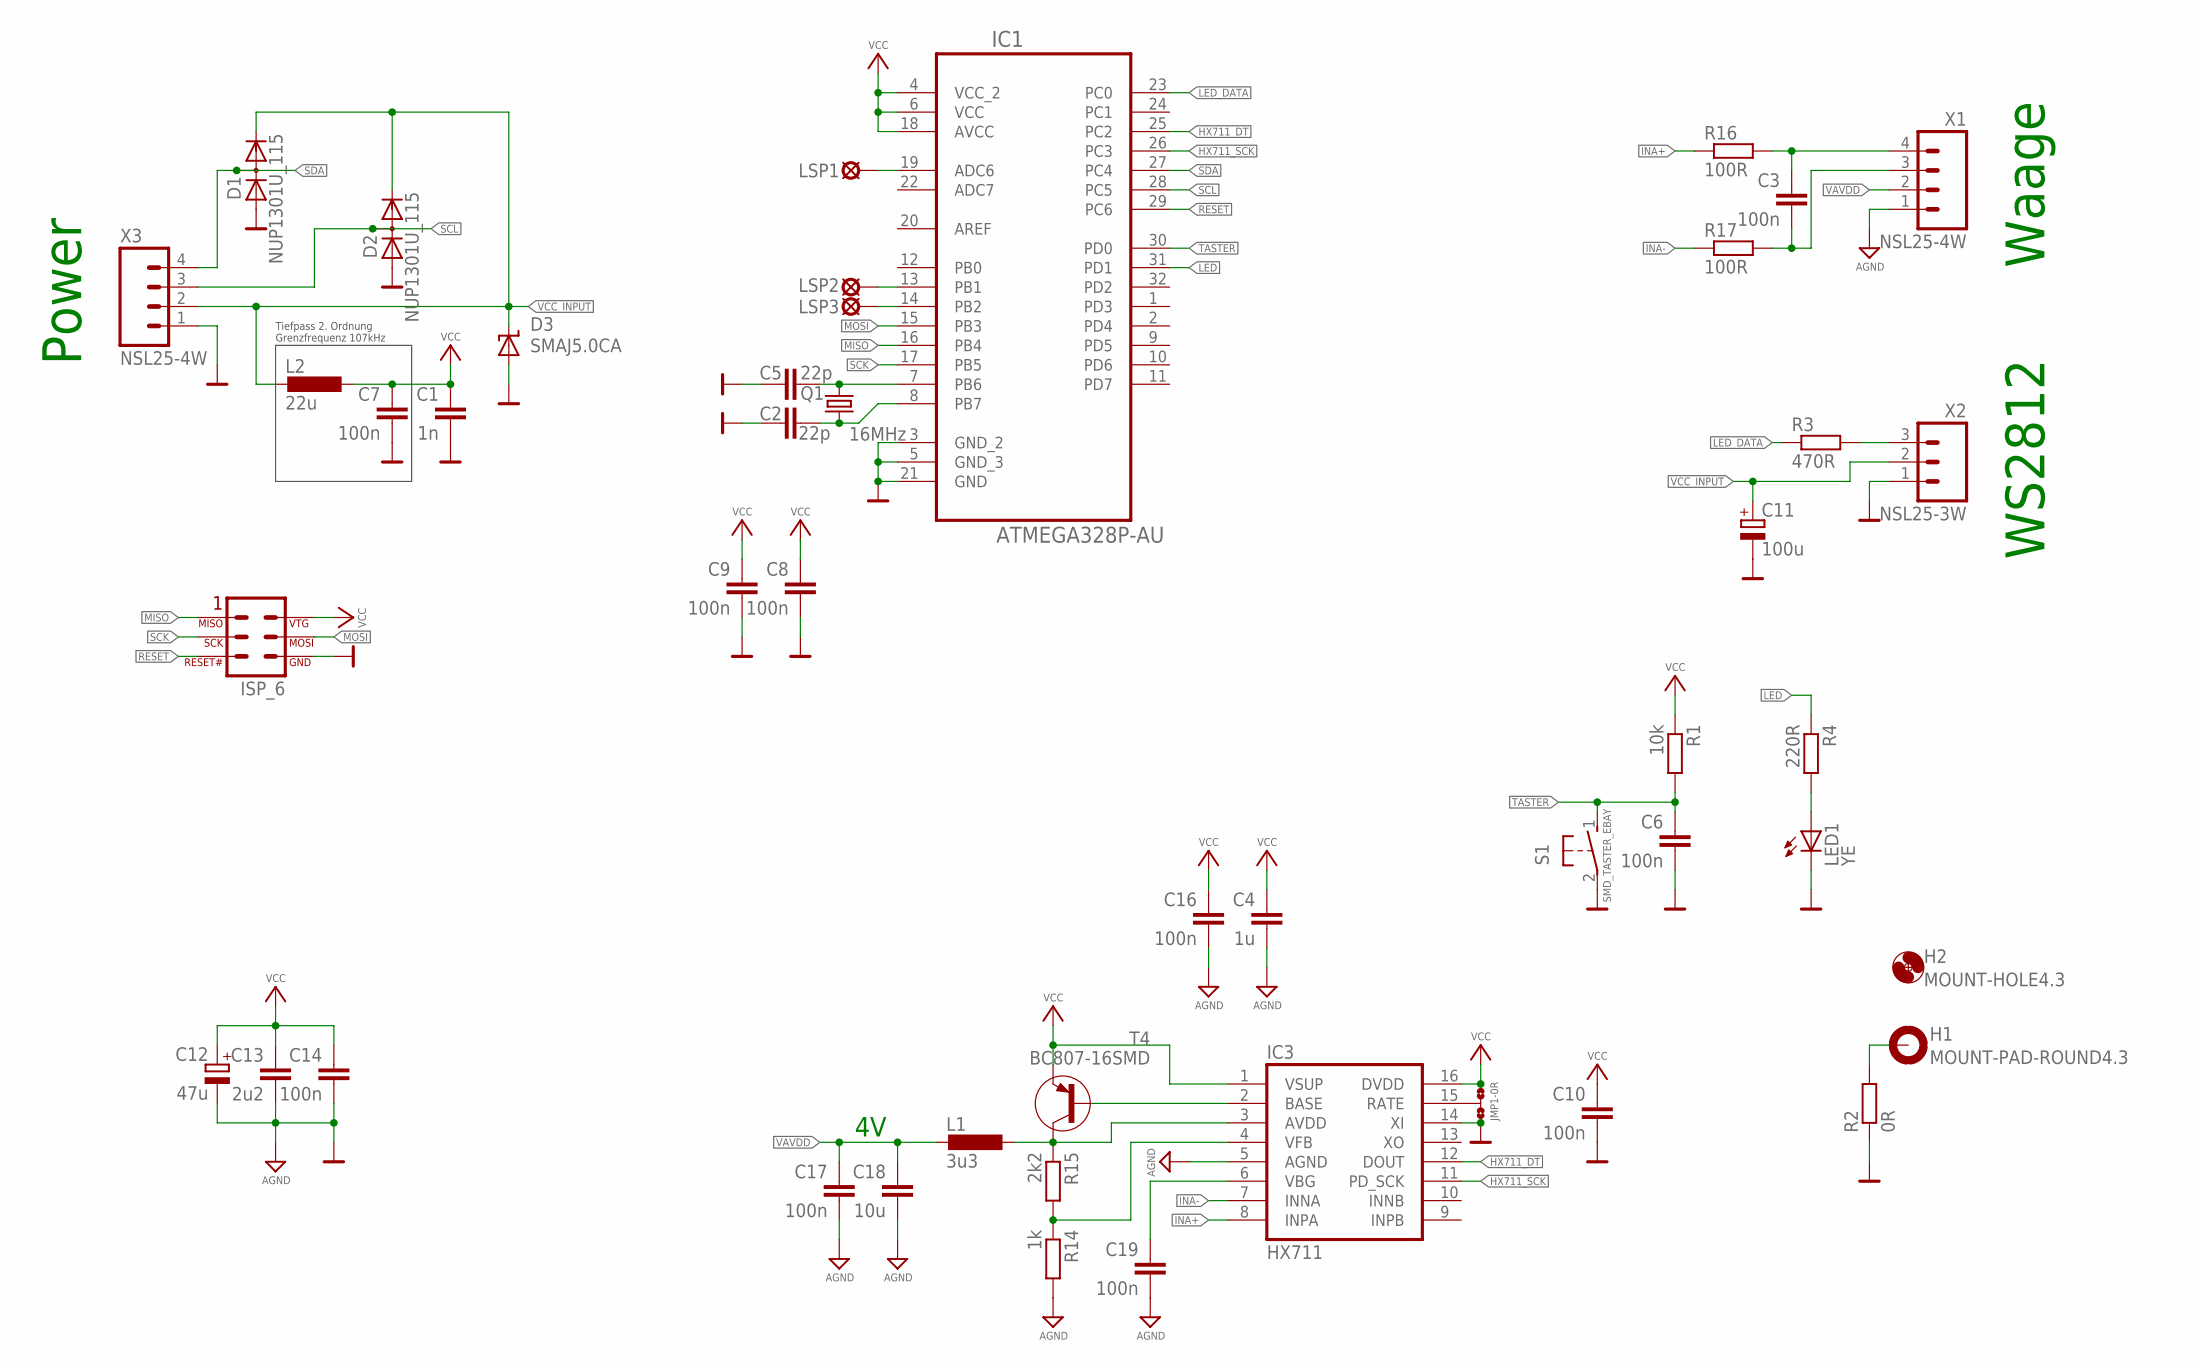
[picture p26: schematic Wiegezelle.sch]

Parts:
C1: 1n; 0805CRH
C2, C5: 22p; 0805CRH
C3, C6, C7, C8, C9, C10, C14, C16, C17, C19: 100n; 0805CRH
C4: 1u; 0805CRH
C11: 100u; 153CLV-0605
C12: 47u; 153CLV-0405
C13: 2u2; 0805CRH
C18: 10u; 0805CRH
D1, D2: NUP1301U_115; SOT323-3
D3: SMAJ5.0CA; SMA-DO214AC
H1: MOUNT-PAD-ROUND4.3; 4,3-PAD
H2: MOUNT-HOLE4.3; 4,3
IC1: ATMEGA328P-AU; QFP80P900X900X120-32N
IC3: HX711; SO16
JMP1: 0R-JUMPA; A0R-JMP
L1: 3u3; 0805CRH
L2: 22u; L4532P
LED1: YE; CHIPLED_0805
LSP1, LSP2, LSP3: LSP06
Q1: 16MHz; HC49UP
R1: 10k; 0805CRH
R2: 0R; 0805CRH
R3: 470R; 0805CRH
R4: 220R; 0805CRH
R14: 1k; 0805CRH
R15: 2k2; 0805CRH
R16, R17: 100R; 0805CRH
S1: SMD_TASTER_EBAY; DTSM3XN
SV1: ATMEL_ISP_6; ML6
T4: BC807-16SMD; SOT23-BEC
X1, X3: NSL25-4W
X2: NSL25-3W

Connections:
AGND: C4.2, C12.-, C13.2, C14.2, C16.2, C17.2, C18.2, C19.2, IC3.5 (AGND), R14.2, X1.1
GND: C1.2, C2.1, C5.1, C6.2, C7.2, C8.2, C9.2, C10.2, C11.-, D1.1, D2.1, D3.A, IC1.3 (GND_2), IC1.5 (GND_3), IC1.21 (GND), IC3.14 (XI), JMP1.3, LED1.C, R2.1, S1.2, SV1.6, X2.1, X3.1
HX711_DT: IC1.25 (PC2), IC3.12 (DOUT)
HX711_SCK: IC1.26 (PC3), IC3.11 (PD_SCK)
INA+: IC3.8 (INPA), R16.1
INA-: IC3.7 (INNA), R17.1
LED: IC1.31 (PD1), R4.1
LED_DATA: IC1.23 (PC0), R3.1
MISO: IC1.16 (PB4), SV1.1
MOSI: IC1.15 (PB3), SV1.4
unnamed: H1.B4,3, R2.2
unnamed: LED1.A, R4.2
unnamed: R3.2, X2.3
unnamed: C5.2, IC1.7 (PB6), Q1.2
unnamed: C2.2, IC1.8 (PB7), Q1.1
unnamed: IC1.19 (ADC6), LSP1.MP
unnamed: IC1.13 (PB1), LSP2.MP
unnamed: IC1.14 (PB2), LSP3.MP
unnamed: IC3.15 (RATE), JMP1.2
unnamed: C19.1, IC3.6 (VBG)
unnamed: IC3.2 (BASE), T4.B
unnamed: IC3.4 (VFB), R14.1, R15.2
unnamed: C3.1, R16.2, X1.4
unnamed: C3.2, R17.2, X1.3
RESET: IC1.29 (PC6), SV1.5
SCK: IC1.17 (PB5), SV1.3
SCL: D2.3, IC1.28 (PC5), X3.3
SDA: D1.3, IC1.27 (PC4), X3.4
TASTER: C6.1, IC1.30 (PD0), R1.2, S1.1 (S)
VAVDD: C17.1, C18.1, L1.2, X1.2
VAVDD_1: IC3.3 (AVDD), L1.1, R15.1, T4.C
VCC: C1.1, C4.1, C7.1, C8.1, C9.1, C10.1, C12.+, C13.1, C14.1, C16.1, IC1.4 (VCC_2), IC1.6 (VCC), IC1.18 (AVCC), IC3.1 (VSUP), IC3.16 (DVDD), JMP1.1, L2.1, R1.1, SV1.2, T4.E
VCC_INPUT: C11.+, D1.2, D2.2, D3.K (C), L2.2, X2.2, X3.2

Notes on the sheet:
Tiefpass 2. Ordnung Grenzfrequenz 107kHz
WS2812
Waage
Power

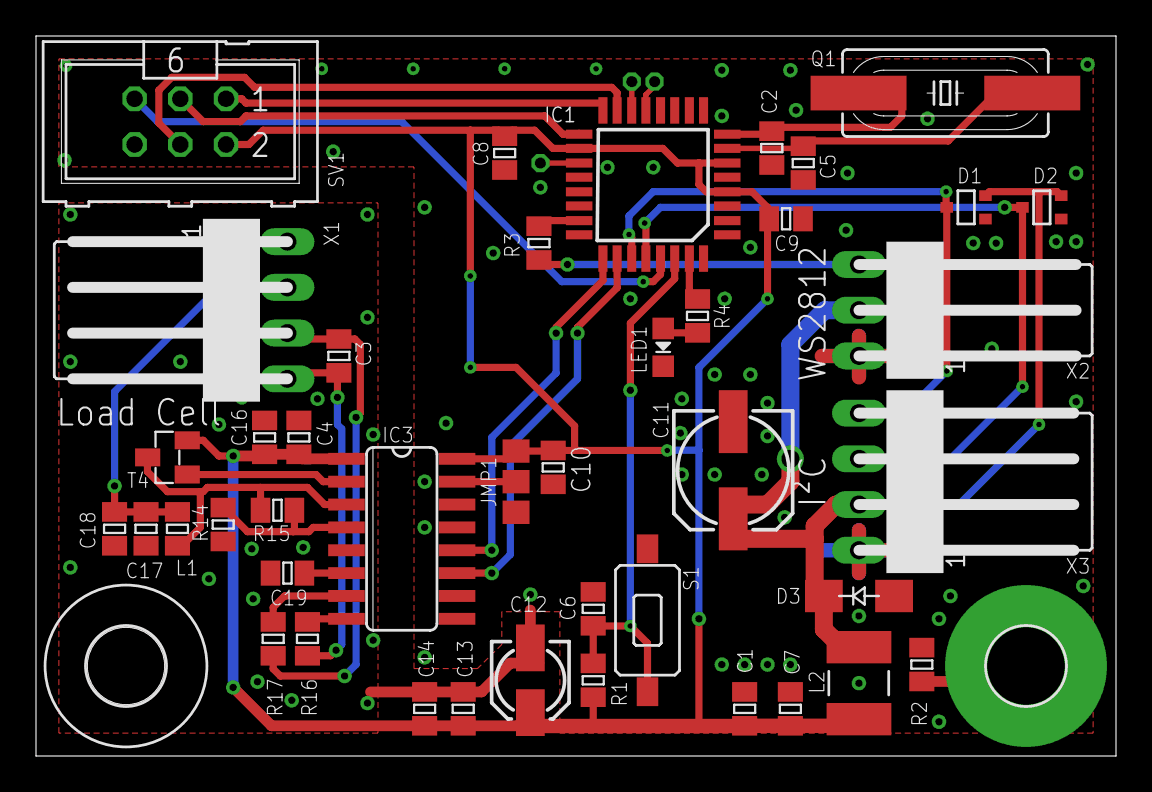
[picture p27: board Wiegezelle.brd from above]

Board: 2 copper layers, 60.0 x 40.0 mm, 47 parts (0 on the bottom side), 33 nets.

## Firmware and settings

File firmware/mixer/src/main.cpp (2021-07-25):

#include <Arduino.h>
#include "Wire.h"
#include "Shared.h"
#include "WireProtocol.h"

#define PIN_EN A7            //ADC7
#define PIN_MOTOR_1 A0       //PC0
#define PIN_MOTOR_2 A1       //PC1
#define PIN_ENDSTOP_TOP 2    //PD2
#define PIN_ENDSTOP_BOTTOM 3 //PD3
#define PIN_MIXER_EN 1       //PD1
#define PIN_MIXER 0          //PD0
#define PIN_LED 4            //PD4
#define PIN_BUTTON 10        //PB2
//not used but still on the PCB
#define PIN_SERVO_1 5 //PD5
#define PIN_SREVO_2 6 //PD6

#define MIXING_MIN_TIME 500      // avoid very short...
#define MIXING_MAX_TIME 5000     // ... and very long mixes
#define MIXING_MOVE_TIMEOUT 3000 //no success if move takes too long
#define MIXING_DEFAULT_TIME 2000 //will be used if no time is set

byte i2c_command = 0xFF;

bool do_mixing;
bool error;
long mixing_time = 1000;

void startMixing(long _mixing_time)
{
  if (do_mixing)
    return;
  error = false;
  do_mixing = true;
  mixing_time = constrain(_mixing_time, MIXING_MIN_TIME, MIXING_MAX_TIME);
  digitalWrite(PIN_LED, HIGH);
}

void stopMixing(bool _error)
{
  error = _error;
  do_mixing = false;
  digitalWrite(PIN_LED, LOW);
}

void handleSetters(int parameters_count)
{
#ifdef SERIAL_DEBUG
  Serial.print("SET");
  Serial.println(i2c_command);
#endif
  switch (i2c_command)
  {
  case MIXER_CMD_START_MIXING:
    if (parameters_count == 0)
    {
      startMixing(MIXING_DEFAULT_TIME);
    }
    else if (parameters_count == 1)
    {
      byte time_in_seconds = Wire.read();
      startMixing((unsigned long)time_in_seconds * 1000);
    }
    break;
  }
}

void handleGetters()
{
#ifdef SERIAL_DEBUG
  Serial.print("GET");
  Serial.println(i2c_command);
#endif
  switch (i2c_command)
  {
  case WIREPROTOCOL_CMD_PING:
    Wire.write(MIXER_BOARD_ADDRESS);
    break;
  case MIXER_CMD_GET_IS_MIXING:
    Wire.write(do_mixing);
    break;

  case MIXER_CMD_GET_SUCCESSFUL:
    Wire.write(!error);
    break;

  //no command byte set or unknown command
  case 0xFF:
  default:
#ifdef SERIAL_DEBUG
    Serial.println("Wrong request");
#endif
    Wire.write(0);
    i2c_command = 0xFF;
    break;
  }
}

void recieved(int count)
{
  //continue only if command byte was set
  if (count < 1)
    return;
  //save the command byte
  i2c_command = Wire.read();
  //handle messages that are only setters
  handleSetters(count - 1);
}

void initWire()
{
  //start i2c communication
  Wire.begin(MIXER_BOARD_ADDRESS);
  //disable pullups for i2c
  digitalWrite(SCL, LOW);
  digitalWrite(SDA, LOW);
  Wire.onReceive(recieved);
  Wire.onRequest(handleGetters);
  WireProtocol::blinkAddress(MIXER_BOARD_ADDRESS, PIN_LED);
}

void setup()
{
#ifdef SERIAL_DEBUG
  Serial.begin(115200);
#endif
  pinMode(PIN_LED, OUTPUT);
  pinMode(PIN_EN, OUTPUT);
  pinMode(PIN_MOTOR_1, OUTPUT);
  pinMode(PIN_MOTOR_2, OUTPUT);
  pinMode(PIN_ENDSTOP_TOP, INPUT);
  pinMode(PIN_ENDSTOP_BOTTOM, INPUT);
  pinMode(PIN_MIXER_EN, OUTPUT);
  pinMode(PIN_MIXER, OUTPUT);
  pinMode(PIN_BUTTON, INPUT_PULLUP);
  //disable the driver
  digitalWrite(PIN_MOTOR_1, HIGH);
  digitalWrite(PIN_MOTOR_2, HIGH);
  digitalWrite(PIN_EN, HIGH);
  digitalWrite(PIN_MIXER_EN, LOW);
  initWire();
#ifdef SERIAL_DEBUG
  Serial.println("Mixer board initialised");
#endif
}

bool isAtTop()
{
  return !digitalRead(PIN_ENDSTOP_TOP) && !digitalRead(PIN_ENDSTOP_TOP);
}

bool isAtBottom()
{
  return !digitalRead(PIN_ENDSTOP_BOTTOM) && !digitalRead(PIN_ENDSTOP_BOTTOM);
}

void startMotor(bool up)
{
  digitalWrite(PIN_MOTOR_1, up ? HIGH : LOW);
  digitalWrite(PIN_MOTOR_2, up ? LOW : HIGH);
}

void stopMotor()
{
  digitalWrite(PIN_MOTOR_1, HIGH);
  digitalWrite(PIN_MOTOR_2, HIGH);
}

void toggleMixer(bool on)
{
  digitalWrite(PIN_MIXER, HIGH);
  digitalWrite(PIN_MIXER_EN, on ? HIGH : LOW);
}

void loop()
{
  //wait for i2c command or button press, stay in top position
  while (!do_mixing && digitalRead(PIN_BUTTON) == HIGH)
  {
    if (!isAtTop())
      startMotor(true);
    else
      stopMotor();
    delay(1);
  }
  if (!do_mixing)
    startMixing(MIXING_DEFAULT_TIME);

  //move down
  startMotor(false);
  unsigned long before_move = millis();
  while (!isAtBottom())
  {
    if (millis() > before_move + MIXING_MOVE_TIMEOUT)
    {
      //TIMEOUT,
      stopMixing(true);
      return;
    }
    delay(1);
  }

  stopMotor();

  //mix
  toggleMixer(true);
  delay(mixing_time);
  toggleMixer(false);

  //move up
  startMotor(true);

  before_move = millis();
  while (!isAtTop())
  {
    if (millis() > before_move + MIXING_MOVE_TIMEOUT)
    {
      //TIMEOUT,
      stopMixing(true);
      return;
    }
    delay(1);
  }

  stopMixing(false);
}

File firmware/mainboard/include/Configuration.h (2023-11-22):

#define LED_STRIPE_PIXELS 60
#define LED_STRIPE_LENGTH_MM 1000
#define DRAFT_PORTS_COUNT 12

#define PUMP_POWER_FREQUENCY 10000
#define PLATFORM_MOTOR_HOMING_SPEED 10000

//Distance of platform center to left corner when homed
#define HOME_DISTANCE 97
#define PUMP_DISTANCE 50
//subtract home distance, so you can set distances from the left corner
#define FIRST_PUMP_POSITION (165 - HOME_DISTANCE)
#define MIXING_POSITION (780 - HOME_DISTANCE)
#define CRUSHER_POSITION (900 - HOME_DISTANCE)
#define SUGAR_POSITION (0 - HOME_DISTANCE)
// the crusher is the last position on the reck
#define PLATFORM_MOTOR_MAXPOS_MM CRUSHER_POSITION

#define PLATFORM_MOTOR_MICROSTEPS 4
#define PLATFORM_MOTOR_FULLSTEPS_PER_MM 200.0 / (20.0 * 2.0)

// PINS //
#define PIN_NEOPIXEL 23

#define PIN_PLATFORM_MOTOR_HOME 18
#define PIN_PLATFORM_MOTOR_DIR 16  //RX2
#define PIN_PLATFORM_MOTOR_STEP 17 //TX2
#define PIN_PLATFORM_MOTOR_EN 4

#define PIN_PUMP_ENABLED 33

#define PIN_IO_RESET 32
#define PIN_IO_CS 15
#define PIN_BUTTON 19
#define PIN_CRUSHER_SENSE 33
#define PIN_SERVO 26
#define PIN_LED 27
// PINS END //

#define GLASS_WEIGHT_MIN 300
#define TOTAL_WEIGHT_MAX 800

#define LEDC_CHANNEL_PUMP 0

//timeout if weight did not increase by a certain amount in the specified time
#define DRAFT_TIMEOUT_MILLIS 3000
#define DRAFT_TIMEOUT_WEIGHT 20

#define ICE_TIMEOUT_MILLIS 5000
#define ICE_TIMEOUT_WEIGHT 10

#define SUGAR_TIMEOUT_MILLIS 3000
#define SUGAR_TIMEOUT_WEIGHT 5

#define CHILD_UPDATE_PERIOD 100

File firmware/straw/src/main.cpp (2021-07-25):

#include <Arduino.h>
#include "Wire.h"
#include "Shared.h"
#include "WireProtocol.h"
#include "Servo.h"

#define PIN_FEEDER_EN 1 //PD1
#define PIN_FEEDER 0    //PD0
#define PIN_LED 4       //PD4
#define PIN_BUTTON 10   //PB2
//not used but still on the PCB
#define PIN_SERVO_STRAW 5   //PD5
#define PIN_SERVO_SHUTTER 6 //PD6

#define SERVO_STRAW_TAKE 0
#define SERVO_STRAW_DISPENSE 95
#define SERVO_SHUTTER_OPEN 0
#define SERVO_SHUTTER_CLOSED 90

#define SERIAL_DEBUG

bool error = false;
bool dispensing = false;

Servo servo_straw;
Servo servo_shutter;

byte i2c_command = 0xFF;

void startDispense()
{
  if (dispensing)
    return;
  error = false;
  dispensing = true;
}

void handleSetters(int parameters_count)
{
#ifdef SERIAL_DEBUG
  Serial.print("SET");
  Serial.println(i2c_command);
#endif
  switch (i2c_command)
  {
  case STRAW_CMD_DISPENSE:
    startDispense();
    break;
  }
}

void handleGetters()
{
#ifdef SERIAL_DEBUG
  Serial.print("GET");
  Serial.println(i2c_command);
#endif
  switch (i2c_command)
  {
  case WIREPROTOCOL_CMD_PING:
    Wire.write(STRAW_BOARD_ADDRESS);
    break;

  case STRAW_CMD_GET_IS_DISPENSING:
    Wire.write(dispensing);
    break;

  case STRAW_CMD_GET_SUCCESSFUL:
    Wire.write(!error);
    break;

  //no command byte set or unknown command
  case 0xFF:
  default:
#ifdef SERIAL_DEBUG
    Serial.println("Wrong request");
#endif
    Wire.write(0);
    i2c_command = 0xFF;
    break;
  }
}

void recieved(int count)
{
  //continue only if command byte was set
  if (count < 1)
    return;
  //save the command byte
  i2c_command = Wire.read();
  //handle messages that are only setters
  handleSetters(count - 1);
}

void initWire()
{
  //start i2c communication
  Wire.begin(STRAW_BOARD_ADDRESS);
  //disable pullups for i2c
  digitalWrite(SCL, LOW);
  digitalWrite(SDA, LOW);
  Wire.onReceive(recieved);
  Wire.onRequest(handleGetters);
  WireProtocol::blinkAddress(STRAW_BOARD_ADDRESS, PIN_LED);
}

void setup()
{
#ifdef SERIAL_DEBUG
  Serial.begin(115200);
#endif
  pinMode(PIN_LED, OUTPUT);
  pinMode(PIN_BUTTON, INPUT_PULLUP);
  //initialize servos
  servo_shutter.attach(PIN_SERVO_SHUTTER);
  servo_shutter.write(SERVO_SHUTTER_CLOSED);
  servo_straw.attach(PIN_SERVO_STRAW);
  servo_straw.write(SERVO_STRAW_DISPENSE);
  //initialize motor
  pinMode(PIN_FEEDER_EN, OUTPUT);
  pinMode(PIN_FEEDER, OUTPUT);
  digitalWrite(PIN_FEEDER, LOW);
  digitalWrite(PIN_FEEDER_EN, HIGH);
  initWire();
#ifdef SERIAL_DEBUG
  Serial.println("Straw board initialised");
#endif
}

void wait(long ms, const char *text)
{
  unsigned long mic = micros();
  for (int i = 0; i < ms; i++)
  {
    Serial.println(text);
    delayMicroseconds(1000 - (micros() - mic));
    mic = micros();
  }
}

void loop()
{
  //wait for i2c command or button press
  while (!dispensing && digitalRead(PIN_BUTTON) == HIGH)
  {
    delay(1);
  }
  dispensing = true;
  digitalWrite(PIN_LED, HIGH);
#ifdef SERIAL_DEBUG
  Serial.println("start dispensing");
#endif
  servo_straw.write(SERVO_STRAW_TAKE);
  delay(1000);
  servo_shutter.write(SERVO_SHUTTER_OPEN);
  delay(500);
  servo_shutter.write(SERVO_SHUTTER_CLOSED);
  delay(500);
  servo_straw.write(SERVO_STRAW_DISPENSE);
  delay(1000);
  digitalWrite(PIN_FEEDER, HIGH);
  delay(3000);
  digitalWrite(PIN_FEEDER, LOW);
#ifdef SERIAL_DEBUG
  Serial.println("dispensing ended");
#endif
  //TODO: error detection
  error = false;
  dispensing = false;
  digitalWrite(PIN_LED, LOW);
}

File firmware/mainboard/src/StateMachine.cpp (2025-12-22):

#include "StateMachine.h"

StateMachine::StateMachine(BalanceBoard *_balance, MixerBoard *_mixer, StrawBoard *_straw_board, CrusherBoard *_crusher, SugarBoard *_sugar_board, MCP23X17 *_mcp, BluetoothSerial *_bt) : balance(_balance), mixer(_mixer), straw_board(_straw_board), crusher(_crusher), mcp(_mcp), bt(_bt), sugar_board(_sugar_board)
{
	startup = true;
	state = BarBotState_t::Idle;
	current_action_start_millis = 0;

	stepper = new AccelStepper(AccelStepper::DRIVER, PIN_PLATFORM_MOTOR_STEP, PIN_PLATFORM_MOTOR_DIR);
	// invert dir pin
	stepper->setPinsInverted(true);
	set_max_speed(100);
	set_max_accel(20);
	set_pump_power(80);
	balance->setCalibration(-1040);
	balance->setOffset(-123865);
}

void StateMachine::begin()
{
	pinMode(PIN_PLATFORM_MOTOR_HOME, INPUT);
	pinMode(PIN_PLATFORM_MOTOR_EN, OUTPUT);
	// enable motor
	digitalWrite(PIN_PLATFORM_MOTOR_EN, LOW);

	pinMode(PIN_BUTTON, INPUT);
	pinMode(PIN_CRUSHER_SENSE, INPUT);
	pinMode(PIN_SERVO, OUTPUT);
	pinMode(PIN_LED, OUTPUT);

	// initialize PWM for the pump on channel 0 with 10 bit resolution and 5kHz
	ledcSetup(LEDC_CHANNEL_PUMP, PUMP_POWER_FREQUENCY, 10);
	ledcAttachPin(PIN_PUMP_ENABLED, LEDC_CHANNEL_PUMP);
	ledcWrite(LEDC_CHANNEL_PUMP, 0);

	init_mcp();

	start_homing();
}

void StateMachine::update()
{
	bool transmit_successful;
	switch (state)
	{
	case BarBotState_t::Idle:
		// we do not check for any errors here!
		balance->update();
		// reset the abort flag on idle
		abort = false;
		break;

	case BarBotState_t::Error:
	case BarBotState_t::ErrorIngredientEmpty:
	case BarBotState_t::ErrorI2C:
	case BarBotState_t::ErrorStrawsEmpty:
	case BarBotState_t::ErrorGlasRemoved:
	case BarBotState_t::ErrorCommunicationToBalance:
	case BarBotState_t::ErrorMixingFailed:
	case BarBotState_t::ErrorCrusherCoverOpen:
	case BarBotState_t::ErrorCrusherTimeout:
	case BarBotState_t::ErrorCommandAborted:
	case BarBotState_t::ErrorSugarDispenserTimeout:
		// nothing to do here
		break;

	/** HOMING START **/
	case BarBotState_t::HomingRough:
		if (!is_homed())
		{
			stepper->run();
			current_microstep--;
		}
		else
		{
			stepper->setCurrentPosition(0);
			stepper->setSpeed(PLATFORM_MOTOR_HOMING_SPEED * PLATFORM_MOTOR_MICROSTEPS);
			set_target_position(100);
			set_state(BarBotState_t::HomingFine);
		}
		break;

	case BarBotState_t::HomingFine:
		// move to fulls step position, so pos = 0 is full step!
		if ((current_microstep % PLATFORM_MOTOR_MICROSTEPS != 0) || is_homed())
		{
			stepper->runSpeed();
			current_microstep++;
		}
		else
		{
			stepper->setCurrentPosition(0);
			stepper->setSpeed(0);
			set_target_position(0);
			set_state(BarBotState_t::Idle);
			if (startup)
				startup = false;
		}
		break;

		/** HOMING END **/

	case BarBotState_t::AbortMovement:
		if (stepper->currentPosition() == stepper->targetPosition())
			set_state(BarBotState_t::ErrorCommandAborted);
		else
			stepper->run();
		break;

	case BarBotState_t::MoveToPos:
		if (abort)
		{
			// decelerrate until stop
			stepper->stop();
			set_state(BarBotState_t::AbortMovement);
		}
		else if (stepper->currentPosition() == stepper->targetPosition())
			set_state(BarBotState_t::Idle);
		else
			stepper->run();
		break;

	case BarBotState_t::Delay:
		if (abort)
			set_state(BarBotState_t::ErrorCommandAborted);
		else if (millis() > (unsigned long)(current_action_start_millis + delay_time))
			set_state(BarBotState_t::Idle);
		break;

	case BarBotState_t::MoveToDraft:
	case BarBotState_t::MoveToCrusher:
	case BarBotState_t::MoveToSugarDispenser:
		if (abort)
		{
			// decelerrate until stop
			stepper->stop();
			set_state(BarBotState_t::AbortMovement);
		}
		else if (stepper->currentPosition() == stepper->targetPosition())
		{
			// draft position is reached
			// get new weight from the balance or throw error
			BalanceUpdateResult_t res = balance->update();
			// TODO: read until weight is stable
			if (res == Balance_DataRead)
			{
				if (balance->getWeight() > GLASS_WEIGHT_MIN)
				{
					draft_timeout_last_check_millis = millis();
					draft_timeout_last_weight = balance->getWeight();
					if (state == BarBotState_t::MoveToDraft)
					{
						start_pump(pump_index, (pump_power_percent * 1024) / 100);
						set_state(BarBotState_t::Drafting);
					}
					else if (state == BarBotState_t::MoveToCrusher)
					{
						if (crusher->StartCrushing())
							set_state(BarBotState_t::CrushingIce);
						else
							set_state(BarBotState_t::ErrorI2C);
					}
					else if (state == BarBotState_t::MoveToSugarDispenser)
					{
						if (sugar_board->StartDispensing())
							set_state(BarBotState_t::DispensingSugar);
						else
							set_state(BarBotState_t::ErrorI2C);
					}
				}
				else
					set_state(BarBotState_t::ErrorGlasRemoved);
			}
			else if (res == Balance_CommunicationError)
				set_state(BarBotState_t::ErrorI2C);
			else if (res == Balance_Timeout)
				set_state(BarBotState_t::ErrorCommunicationToBalance);
		}
		else
			stepper->run();
		break;
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

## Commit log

2019-04-01 I2C communication moved to shared
2019-04-01 Wrong i2c command fixed
    [main.cpp]
2019-04-04 LED controller for balance pcb added
2019-04-08 BalanceBoard class created, code moved
    [Configuration.h]
2019-04-08 Basic state machine added
    [Configuration.h]
2019-04-10 Revert "Protocol upgraded with state machine support_2"
    This reverts commit b019bc0e1c483c602313dabbec1935119e7cba01.
    [LEDController.h, StateMachine.cpp, main.cpp]
2019-04-10 Switched to FastLED, LED Animations added
2019-04-17 Balance board introduced to StateMachine
    [Configuration.h]
2019-05-06 Error handling added to protocol
    [StateMachine.cpp, main.cpp]
2019-05-22 I2C communication moved to class WireProtocol
2019-05-22 New hardware
    [Configuration.h]
2019-05-24 Communication between server and arduino updated
    [Configuration.h]
2019-05-28 Balance board changed to Neopixel
2019-05-30 LED Controller for mainboard reworked
    [Configuration.h]
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2019-05-31 Minor bugfixes in communication
    [StateMachine.cpp, main.cpp]
2019-07-29 Mixer Board support added
2019-09-15 Logging enabled, prints removed
2019-09-26 Bugfixes from first real startup
    [Configuration.h]
2019-10-24 New PCBs and display added
    [Configuration.h]
2019-11-01 - MCP23S17 as pump driver - Display support improved
    [Configuration.h]
2019-11-11 Pump index based lighting added
    [Configuration.h]
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2019-11-17 Mainboard: I2C Communication improved
    [Configuration.h]
2019-11-17 New milled straw dispenser board
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2019-12-08 New config. Pi can now set balance calibration
    [Configuration.h]
2019-12-20 Mixer board reworked, it is now independent
    [Configuration.h]
2019-12-20 New PCB for straw dispenser
2019-12-30 New positions with new hardware
    [Configuration.h]
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2019-12-30 Bugfix: Mixer board signaled finish to early
    [main.cpp]
2020-01-10 Automated finding of bluetooth device added
2020-03-31 Crusher board firmware added
2020-03-31 Mainboard and balance folders made lower case
    [Configuration.h]
2020-04-01 Crusher functionality added to mainboard
    [Configuration.h]
2020-04-01 Automated search for bluetooth device
2020-05-03 CAD: Version 0.0
    [DT-006_Pumpenhalterung.stl, DT-007_Teller_Teil1.stl, DT-013_Box Wiegeplatine.stl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]
2020-05-03 CAD: BOM initial commit
    [BOM.xlsx]
2020-05-06 PCBs V1.0
    [Mainboard.brd, Mainboard.sch, Mixer.brd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]
2020-05-07 CAD:Dichtung entfernt,Teile angepasst
    [Abeckblech Pumpen.psm, BOM.xlsx, DT-007_Teller_Teil1.stl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]
2020-05-09 FT-Teil hinzugefügt
    [BOM.xlsx]
2020-05-14 BOM:Artikel hinzugefügt
    [BOM.xlsx]
2020-05-17 CAD:release: Schlitten, Pumpe,Rührer und Rahmen
    [Abeckblech 2.psm, Abeckblech Pumpen.psm, DT-001_Schrittmotorhalter.stl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]
2020-06-05 BOM: Filamentbedarf für Druckteile hinzugefügt
    [BOM.xlsx]
2020-07-31 Teile hinzugefügt
    [BOM.xlsx, DT-025_Reibrad.stl]
2020-08-08 BOM für Rührer nachgebessert
    [BOM.xlsx]
2020-08-12 BOM: Rollenschalter von Schlitten nach Rahmen
    [BOM.xlsx]
2020-10-15 Durchmesser angepasst
    [BOM.xlsx, DT-020_Zahnrad.stl, DT-024_Strohhalmmagazin .stl]
2020-10-15 Teil hinzugefügt
    [BOM.xlsx]
2020-10-17 Barbot handles config, new balance calibration GUI
2020-10-17 Balance calibration in config renamed
2020-10-23 Bugfix for new Raspberry Pi OS
2020-10-25 Position of pumps and mixer adjusted
    [Configuration.h]
2020-10-28 Balance folder with wrong capital name removed
    [LEDController.cpp, LEDController.h, main.cpp]
2020-11-01 Search for BT device moved to state machine
2021-03-18 New board for crusher
2021-04-02 Ice, straw and stirring added as icon buttons
2021-04-03 Single ingredient view with nice icon buttons
2021-04-03 Electronics folder resturctured
    [Mainboard.brd, Mainboard.sch, Mixer.brd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]
2021-07-31 Check for connected boards at startup
2021-07-31 Show connected boards in admin overview
2021-08-08 Different timeout for ice crushing
    [Configuration.h]
2021-08-15 Minor fix in mainboard firmware
    [main.cpp]
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2021-08-16 Blocking set and get command implemented for I2C
2021-08-20 CAD: Crusher hinzugefügt
    [Abeckblech 2.psm, Abeckblech Pumpen.psm, Abwicklung für KT-026 Abdeckblech Pumpen.psm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]
2021-08-26 Bugfix: Balance calibration
2021-08-26 Bugfix: Async set for balance calibration
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2022-06-25 Files for raspberry pi moved to separater folder
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2022-08-05 Bugfix: Crusher hardware pins were wrong
    [main.cpp]
2022-09-11 Bugfix: Crusher UART interfered with safety switch
    [main.cpp]
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2023-09-24 Support for sugar dispenser added to mainboard
    [Configuration.h]
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2023-11-22 mainboard: LED stripe position indication updated
    [Configuration.h]
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2024-06-14 Fix: Missing buttons in order screen
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2026-02-06 fix: Correct keyboard button text updates and add new GUI tests for controls, busy view, and main window components.
2026-02-10 feat: Implement Python virtual environment setup and enhance Raspberry Pi detection in the installation script.
2026-02-14 refactor: Clear user messages after user input, adjust board check abort behavior, and enhance the application restart mechanism.
2026-02-14 feat: Mock a connected balance board and streamline the board connection check flow.
2026-02-14 refactor: Update Raspberry Pi detection to read the device tree model instead of the nodename.
2026-02-14 feat: Enhance `SelectorButton` with `currentData` and `currentIndexChanged` for `QComboBox` compatibility, and utilize it for date and ingredient selections.
2026-02-14 style: Remove fixed minimum height for buttons in the list selector.
2026-02-14 feat: Initialize BusyView with the current barbot message and add a corresponding test.
2026-02-14 fix: Adjust Wayland display rotation and X11/udev touch input calibration matrices.
2026-02-15 refactor: streamline Raspberry Pi setup by integrating screen rotation directly into Wayland autostart for Bookworm and Trixie, removing the generic touch rotation script and LXDE configuration.
2026-02-21 refactor: Adjust `QScroller` properties for improved scroll/click distinction and refine event filtering to block events only on the ListSelector itself.
2026-02-28 feat: Add comprehensive logging for events and button clicks within the `ListSelector` for debugging.
2026-02-28 refactor: Remove debugging logs and event filtering, and refine QScroller properties for improved touchscreen interaction.
2026-02-28 feat: Reimplement Bluetooth communication using native sockets and remove PyBluez dependency.
2026-02-28 feat: Add a button to reset the MAC address in admin settings.
2026-02-28 chore: Add detailed logging for Bar Bot Bluetooth device discovery, including search start, device enumeration, and success/failure states.
2026-02-28 feat: Improve Bluetooth device discovery with scanning and add automatic pairing on connection failure.
2026-03-07 fix: Typo in filename
    [MCP23X17.cpp]
